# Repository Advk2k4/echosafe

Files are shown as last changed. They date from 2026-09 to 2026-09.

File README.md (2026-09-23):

# EchoSafe

Wearable, around-the-ear sound-alert device for people who are deaf or hard
of hearing. ESP32-S3, 4 directional MEMS mics, on-device ML sound
classification, 4 directional haptic motors.

See [`CLAUDE.md`](CLAUDE.md) for architecture, pin mapping, ML pipeline, and
current status. See [`CONSOLIDATION_NOTES.md`](CONSOLIDATION_NOTES.md) for
where this repo's contents came from.

```
firmware/   ESP32-S3 Arduino sketches (full system, single-mic reference, data collector)
ml/         Training pipeline + dataset
hardware/   5 KiCad projects: central pod + 4 earpiece modules (PCB layout not yet started)
docs/       Supplementary reference docs
```

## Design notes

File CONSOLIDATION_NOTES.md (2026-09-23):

# Consolidation Notes

This repo was assembled from several scattered folders under `~/Documents/`
on 2026-09-11. Nothing in the original folders was deleted or moved — only
copied. This file records what came from where, and what was deliberately
left out.

## Brought in

| Source | Went to | Notes |
|---|---|---|
| `EchoSafe_ML/echosafe_full_system/` | `firmware/echosafe_full_system/` | Most recently modified firmware, primary target |
| `EchoSafe_ML/echosafe_inference/` | `firmware/echosafe_inference/` | Kept as minimal bring-up reference; `echosafe_full_system.ino` depends on this folder via relative include — keep them siblings |
| `EchoSafe_ML/echosafe_feature_collector/` | `firmware/echosafe_feature_collector/` | Data collection firmware |
| `EchoSafe_ML/mic_oldML.c` | `firmware/mic_oldML.c` | Historical reference, copied verbatim |
| `EchoSafe_ML/uploadLittleFS.ino` | `firmware/uploadLittleFS/uploadLittleFS.ino` | Debug utility (moved into its own sketch folder 2026-09-22 so arduino-cli can compile it in place) |
| `EchoSafe_ML/data/*.wav` | `firmware/data/` | Alert sound files |
| `EchoSafe_ML/retrain.py`, `train_on_esp32_features.py`, `download_sounds.py`, `play_sound.py`, `serial_logger.py`, `quick_start.py` | `ml/` | ML pipeline scripts |
| `EchoSafe_ML/echosafe_dataset.npz` | `ml/echosafe_dataset.npz` | 1059-sample dataset, current |
| `EchoSafe_ML/IMPLEMENTATION_SUMMARY.md` | `docs/IMPLEMENTATION_SUMMARY.md` | Data collection strategy reference |
| `EchoSafe_RevA/` (entire folder) | `hardware/EchoSafe_RevA/` | Copied wholesale to preserve KiCad's relative-path project structure |

## Deliberately left out (and why)

- **`EchoSafe_ML/echosafe_fixed/echosafe_fixed.ino`** and
  **`EchoSafe_ML/final_test/final_test.ino`** — earlier drafts in the same
  lineage as `echosafe_full_system.ino`, superseded by it (confirmed by
  file mtimes and near-total diff overlap). Left in the original
  `EchoSafe_ML/` folder if ever needed for reference.
- **`EchoSafe_ML/trained_models/`** — two training snapshots from
  2026-02-12 using a `barks` class (not `gunshots`) on a ~361–373-sample
  dataset, predating the current 1059-sample/`gunshots` dataset. Stale.
- **`EchoSafe_ML/sounds/`** (~1.6GB, ESC-50 + playback sounds) — not
  copied due to size; regenerate locally via `python ml/download_sounds.py
  --dataset esc50 --output sounds/` if you need it for further data
  collection.
- **`EchoSafe_Audio/`** — an older/parallel ML effort: 16 hand-picked
  features (13 MFCCs + spectral centroid + bandwidth + zero-crossing-rate)
  instead of the current 403-feature pure-MFCC approach, different class
  set (`barks`, `VehicleApproaching` — not in the current 5-class set),
  lower accuracy (88.89% vs. 97.5%). Superseded, not merged in.
- **`EchoSafeTesting/`** — empty except for `.DS_Store`. Not carried
  forward.

## Known issues surfaced during consolidation (not yet fixed)

- **TL-mic workaround applied (2026-09-11):** `echosafe_full_system.ino`'s
  own comments documented a dead top-left (TL) mic (0.0000 RMS on last
  contact). `ML_MIC_CHANNEL` has been switched from `ONLY_LEFT` to
  `I2S_CHANNEL_FMT_ONLY_RIGHT` to match the documented workaround. This is
  a software mitigation, not a hardware fix — verify TL's actual state
  during bring-up. Also newly confirmed: `model_weights.h` was trained on
  the single-mic reference rig's audio (GPIO 5/6/7), not on either array
  channel, so real accuracy recovery requires retraining on array audio,
  not just this channel flip.
- **No PCB has ever been laid out or fabricated** for RevA — the KiCad
  `.kicad_pcb` file is empty. Any physical bring-up needs a breadboard/
  dev-kit setup, not an assembled board.
- **(Fixed 2026-09-11)** RevA schematic had no signal-level wiring at all.
  Added all I2S (2× mic pairs + speaker), I2C (mux + 4 haptic drivers),
  motor-output, and relevant power/enable nets via global labels (matching
  the sheet's existing power-rail label convention). Initial mic/motor
  quadrant assignment was a guess (numeric order); confirmed with the user
  same day as clockwise (MIC1/M1=TL, MIC2/M2=TR, MIC3/M3=BR, MIC4/M4=BL)
  and the wiring corrected to match — see CLAUDE.md's hardware section for
  full details of what changed and why.
- **(Fixed 2026-09-11)** Added C6-C9 (0.1µF decoupling caps) for each
  DRV2605's REG pin, per datasheet recommendation.
- **(Decided 2026-09-11, confirmed final)** Speaker architecture: 1×
  MAX98357A driving both 8Ω speakers in parallel (4Ω combined, within
  spec) — no second amp needed.
- **(Added, then replaced, 2026-09-11)** A placeholder USB-C connector was
  wired to the NPM1300 PMIC's native VBUS/CC1/CC2 pins, then removed the
  same day once the real power architecture was confirmed. No power switch
  or button added — confirmed out of scope for this design.
- **(Replaced 2026-09-11) Power architecture overhaul:** NPM1300 PMIC
  removed entirely (it was never actually wired even in the original
  pre-consolidation schematic — confirmed before deleting it) and replaced
  with the user's actual intended parts: J1 = TP4056_Module (HiLetGo,
  w/ protection), LD1 = LD1117V33 (SparkFun breakout), BT1 = 3.7V 350mAh
  LiPo. The three previously-separate rails (3V3_SYS/3V3_AUDIO/1V8_MIC)
  were consolidated into one 3V3_SYS rail from the single LD1117V33 —
  mics moved from a planned 1.8V supply to 3.3V (within ICS-43434 spec).
  Full capacitor mapping (C1-C17, all values and purposes) is in
  CLAUDE.md's "Power Architecture" section, including a correction: the
  DRV2605 REG-pin caps were originally set to 0.1µF (my initial guess);
  TI's datasheet actually specifies 1.0µF, corrected as part of this pass.
- **(Confirmed 2026-09-11) Board partition:** 4 earpiece modules (front-L/
  front-R each with 1 mic + 1 motor + 1 speaker + that mic's own
  decoupling cap; rear-L/rear-R each with just 1 mic + 1 motor + cap)
  plus 1 central pod holding everything else (ESP32, amp, mux, all 4
  haptic drivers, charging/regulation, battery, remaining caps).
- **(Added 2026-09-11) Harness connectors J2-J5**, one per earpiece
  module, documenting exact wire count (9 pins front/with speaker, 7
  pins rear/without) using **star topology** (confirmed with the user):
  a separate cable per module rather than one cable daisy-chaining
  through both mics on a shared I2S bus. The electrical nets are
  identical either way — the choice only affects cable routing and
  pod-side pin count. See CLAUDE.md for the full per-connector pin list.
- **(Done 2026-09-12) Split into 5 separate KiCad projects.** MIC1-4,
  M1-4, LS1-2, and their decoupling caps (C9-C12) moved out of
  `EchoSafe_RevA` (now specifically the central pod) into 4 new small
  projects: `EchoSafe_FrontLeft`, `EchoSafe_FrontRight`,
  `EchoSafe_RearLeft`, `EchoSafe_RearRight`. All 5 share one library
  folder (`EchoSafe_RevA/lib/symbols/`) via relative `sym-lib-table`
  paths — nothing duplicated. Each module connects to the pod's J2-J5
  connectors via a matching local `J1` using the same net names (a
  documentation convention, not an automatic cross-project link — the
  real connection is the physical cable). See CLAUDE.md's "Multi-Board
  Project Structure" section for the full breakdown.
- **(Clarified 2026-09-11)** `EchoSafe_v1_mech_layout.png` is outdated,
  disregard it. `EchoSafe.png` is the actual target look, minus the
  in-ear-bud cable shown in that render — speakers mount in the behind-
  ear housings instead.
- **(Done 2026-09-12) Footprints assigned across all 5 projects**,
  target confirmed as a compact near-final wearable (not an early
  bring-up prototype). Found and fixed two real bugs along the way:
  (1) the project split had silently wiped the mic/motor footprints that
  already existed pre-split — the instance generator zeroed every new
  component's footprint unconditionally, restored from the pre-split
  commit; (2) **footprint library registration (`fp-lib-table`) never
  existed in any version of this project** — same class of gap as the
  `sym-lib-table` issue found earlier — created it for all 5 projects and
  fixed the bare (unprefixed) footprint names that could never have
  resolved without it. Full per-part footprint table and reasoning is in
  CLAUDE.md's "Footprints" section. Footprints across all 5 projects are now fully assigned as of
  2026-09-13: LS1/LS2 = DigiKey 1528-4227-ND = Adafruit #4227 Mini Oval
  Speaker, 8Ω/1W/30x20x5mm, verified via DigiKey/Adafruit listings, not
  from memory. Connects via a Molex PicoBlade 1.25mm 2-pin connector
  (not bare wire) — footprint set to the matching PicoBlade receptacle,
  confirmed against KiCad's own footprint library source.
- **(Verified 2026-09-13)** The JST-SH harness connector footprint
  names from last session were flagged as unverified — checked them
  against KiCad's own footprints repo and found the guess was wrong
  (`BM0xB-SRSS-TB` prefix instead of the real `SM0xB-SRSS-TB`). Fixed
  all 8 occurrences across all 5 projects. Also checked TP4056 module
  pin spacing against multiple independent sources; 2.54mm/0.1"
  through-hole is standard, matching what was already assigned —
  worth a physical check against the actual board once it's in hand.
- **(Critical fix, 2026-09-13) Session-wide Y-axis coordinate bug.**
  Discovered KiCad is actually installed on this machine and ran real
  `kicad-cli sch erc` against every schematic for the first time —
  found that every label/wire/no-connect placed this session with a
  nonzero local Y pin offset used the wrong sign (`placement_y +
  local_y` instead of the correct `placement_y − local_y`, per
  KiCad's Y-up-symbol/Y-down-sheet convention). Fixed via a from-
  scratch single-pass correction across all 5 projects, verified by
  ERC before/after (all 4 modules: 21/21/17/17 → 9/9/8/8 violations,
  all now expected; central pod: down to 0 dangling labels / 0
  genuinely unconnected pins). Also fixed along the way: the ESP32's
  own 3V3/GND/EN pins had never been wired to anything (every
  peripheral got connected, the MCU's own supply pins were missed) —
  added the EN RC delay circuit per Espressif's actual hardware
  design guidelines (fetched, R=10k/C=1uF), and tied #PWR01 (an
  orphaned GND flag left over from the removed NPM1300) to GND. Full
  writeup in CLAUDE.md's "Critical fix" section, including the
  transform formula for anyone hand-editing .kicad_sch again.
- **(Replaced 2026-09-13) Mic footprint (`LGA_CAV_IVS`) didn't match
  the real part.** Found while starting PCB placement: the original
  SnapEDA-imported footprint (pre-dates this session) had GND as a
  tiny 0.127mm corner pad and an off-by-one pad numbering issue
  (a mechanical hole occupying pad "6", pushing the real 6th
  electrical pad to "7"). Checked against InvenSense's actual
  datasheet (DS-000069, fetched this session): GND is really a large
  ring pad around the acoustic port. Authored a replacement footprint
  (`ICS-43434_LGA6`) via KiCad's own `pcbnew` Python API directly from
  the datasheet's dimensions, round-trip verified by reloading it.
  Updated all 4 module projects' `fp-lib-table` and MIC1-4's
  `Footprint` property. One thing not expressible in a footprint file:
  the datasheet also calls for a drilled acoustic port hole through
  the PCB itself at this location — flagged in CLAUDE.md as a manual
  layout step, not something a footprint can encode.
- **(Fixed 2026-09-11)** RevA was missing 3 of 4 DRV2605 haptic drivers and
  the TCA9548A I2C mux the firmware architecture requires. Added U5
  (TCA9548A, verified pinout from TI datasheet SCPS207F) and U6/U7/U8
  (DRV2605LDGS, duplicated from the existing working U3). Placed only —
  not wired to the ESP32 or to each other yet.
- **(Fixed 2026-09-11)** `hardware/EchoSafe_RevA/EchoSafe_RevA/sym-lib-table`
  pointed at files that never existed, even in the original folder pre-
  dating this consolidation, plus 2 of 5 library nicknames didn't match
  the `lib_id` prefixes actually used in the schematic. Corrected to real
  files via `${KIPRJMOD}`-relative paths. Previously any attempt to place
  a *new* instance of these parts in KiCad would have failed; existing
  placements worked only because `.kicad_sch` caches symbols inline.
- The original `EchoSafe_ML/CLAUDE.md` documented `echosafe_inference.ino`
  as having WAV playback / LittleFS / a fuller command set — the actual
  current file has none of that (mic + inference only). Fixed in this
  repo's `CLAUDE.md`.
- `EchoSafe_ML/` had no `.gitignore` despite its own docs claiming one
  excluded `*.npz` etc. This repo has a real one.

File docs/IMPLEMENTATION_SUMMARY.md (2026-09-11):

# EchoSafe Implementation Summary

## What We've Built

A complete end-to-end system for collecting real-world audio features directly from your ESP32 and training a classifier that **perfectly matches** the deployment environment.

## Key Innovation

**Problem**: Training on librosa features ≠ ESP32 features → poor accuracy
**Solution**: Collect features FROM the ESP32 → Train on exact same distribution → Perfect match!

---

## Files Created

### 1. **echosafe_feature_collector.ino** (ESP32 Firmware)
- Captures audio from I2S MEMS microphone
- Extracts MFCC features on-device
- Outputs features via serial in structured format
- **Commands**: 
  - `c` - Capture one sample
  - `r` - Start continuous recording (every 2s)
  - `s` - Stop continuous recording

### 2. **serial_logger.py** (Data Collection)
- Connects to ESP32 via serial
- Captures feature vectors in real-time
- Prompts for labels
- Builds labeled dataset (.npz format)
- **Interactive commands**:
  - `c` - Capture one sample
  - `a` - Auto-capture mode
  - `s` - Save and show stats
  - `q` - Save and quit

### 3. **download_sounds.py** (Dataset Downloader)
- Downloads ESC-50 environmental sound dataset
- Organizes sounds by category
- Creates folders for custom recordings
- Lists recommended categories for safety/wearable devices

### 4. **play_sound.py** (Sound Playback)
- Plays sounds through speakers for mic capture
- Interactive category browser
- Batch playback with configurable pauses
- Can record ambient silence samples

### 5. **train_on_esp32_features.py** (Model Training)
- Trains on ACTUAL ESP32 features
- Automatic train/val/test split
- Feature standardization
- Exports trained model
- **Optional**: Exports model as C code for ESP32

### 6. **README.md** (Complete Guide)
- Full workflow documentation
- Hardware setup instructions
- Troubleshooting guide
- Best practices

### 7. **quick_start.py** (Setup Assistant)
- Checks dependencies
- Guides through first collection
- Interactive setup wizard

---

## Recommended Sound Datasets

### 1. **ESC-50** (Best for General Environmental Sounds)
- **Source**: https://github.com/karolpiczak/ESC-50
- **Size**: ~600MB, 2,000 sounds
- **Categories**: 50 classes including:
  - Animals: dog, cat, rooster, bird
  - Natural: rain, wind, water, thunder
  - Human: crying baby, coughing, sneezing, footsteps
  - Interior/Domestic: door knock, keyboard, clock alarm, vacuum
  - Urban: siren, car horn, engine, helicopter
- **Download**: `python download_sounds.py --dataset esc50`

### 2. **UrbanSound8K** (Urban/City Sounds)
- **Source**: https://urbansounddataset.weebly.com/urbansound8k.html
- **Size**: ~6GB, 8,732 sounds
- **Categories**: Air conditioner, car horn, children playing, dog bark, drilling, engine idling, gun shot, jackhammer, siren, street music
- **Use case**: Safety/alert sounds for wearable
- **Download**: Manual download from website (requires citation agreement)

### 3. **FSD50K** (Freesound Dataset)
- **Source**: https://zenodo.org/record/4060432
- **Size**: ~50GB, 51,197 sounds
- **Categories**: 200 classes from AudioSet ontology
- **Use case**: Most comprehensive for any domain
- **Download**: From Zenodo (large!)

### 4. **AudioSet** (Google's Audio Dataset)
- **Source**: https://research.google.com/audioset/
- **Size**: ~2 million YouTube clips
- **Categories**: 632 classes (very comprehensive)
- **Use case**: When you need very specific sounds
- **Download**: Requires YouTube downloading (complex)

### 5. **Freesound.org** (Individual Sounds)
- **Source**: https://freesound.org/
- **Best for**: Custom, specific sounds
- **Search**: By keyword, browse by category
- **License**: Various (check individual sounds)
- **Use case**: When datasets don't have what you need

---

## Recommended Sound Categories for EchoSafe

Based on safety/wearable use case:

### High Priority (Collect First)
```
✅ Emergency Sounds
   - siren (police, ambulance, fire)
   - car_horn
   - alarm_clock / alarm_bell
   - glass_breaking
   
✅ Human Alerts
   - crying_baby
   - screaming (if available)
   - coughing
   - sneezing
   
✅ Environmental Alerts
   - dog_bark (aggressive vs friendly)
   - door_knock
   - doorbell
   
✅ Background/Calibration
   - silence (ambient room noise)
   - white_noise
   - rain
   - keyboard_typing
```

### Medium Priority
```
🔸 Activity Sounds
   - footsteps
   - clapping
   - vacuum_cleaner
   - washing_machine
   
🔸 Mechanical
   - engine
   - drilling
   - chainsaw
   - hand_saw
```

### Custom/Domain-Specific
```
🔹 Record Your Own
   - Specific alarm sounds in your environment
   - Voice commands ("help", "emergency")
   - Equipment-specific sounds
   - Environmental sounds unique to deployment location
```

---

## Data Collection Strategy

### Phase 1: Download ESC-50
```bash
python download_sounds.py --dataset esc50 --output sounds/
```

### Phase 2: Organize Priority Sounds
```bash
python play_sound.py --interactive sounds/playback_sounds
```

Pick categories from ESC-50:
- dog_bark
- siren
- car_horn
- crying_baby
- alarm_clock
- glass_breaking
- door_knock

### Phase 3: Record Custom Sounds

**Silence (Most Important!)**:
```bash
# Record ambient noise in your deployment environment
python play_sound.py --record-silence --silence-duration 2 --silence-output silence_001.wav

# Record 20-30 different silence samples:
# - Different rooms
# - Different times of day
# - With/without HVAC
# - With/without background conversation
```

**Custom Alarms/Alerts**:
```bash
# Create category for your specific alarm
python download_sounds.py --dataset custom --custom-name "my_alarm"

# Record your actual alarm sound:
# - Play through speaker
# - Record directly to .wav file (16kHz mono recommended)
# - Place in sounds/custom_recordings/my_alarm/
```

### Phase 4: Systematic Collection

**Recommended workflow**:

1. **Start with 6 core classes** (20-30 samples each):
   - silence
   - dog_bark
   - siren
   - car_horn
   - alarm_clock
   - crying_baby

2. **Vary conditions**:
   - Near (0.5m), medium (2m), far (5m) distances
   - Low, medium, high volumes
   - With/without background noise
   - Different angles

3. **Collection tips**:
   - Position speaker at consistent distance from mic
   - Label consistently (use same names!)
   - Take breaks every 10-15 samples
   - Verify features look good in serial output

---

## Expected Performance

With good data collection:

| Metric | Expected Value |
|---|---|
| Training Accuracy | 95-99% |
| Validation Accuracy | 90-95% |
| Test Accuracy | 85-93% |
| Inference Time (ESP32) | 50-150ms |

**If accuracy is lower**:
- Collect more samples (aim for 30-50 per class)
- Ensure high audio quality
- Check label consistency
- Increase model size: `--hidden 256 128 64`

---

## Complete Workflow Timeline

### Day 1: Setup (1-2 hours)
- Upload firmware
- Verify I2S microphone works
- Download ESC-50 dataset
- Test capture with `c` command

### Day 2-3: Data Collection (4-6 hours)
- **Session 1**: Silence class (30 samples, 1 hour)
  - Record ambient noise in different conditions
- **Session 2**: ESC-50 sounds (3-4 classes, 2 hours)
  - Play sounds, capture, label
- **Session 3**: More ESC-50 sounds (3-4 classes, 2 hours)
- **Session 4**: Custom sounds (1-2 classes, 1 hour)

### Day 4: Training (1 hour)
- Train model on collected features
- Evaluate performance
- Identify weak classes → collect more data if needed

### Day 5: Refinement (2-3 hours)
- Collect additional samples for low-accuracy classes
- Retrain
- Export model to C code
- Create inference firmware

### Week 2: Deployment & Testing
- Deploy to ESP32
- Real-world testing
- Fix edge cases
- Final tuning

---

## Key Success Factors

### ✅ DO:
1. **Always collect a "silence" class** with ambient noise
2. **Use consistent label names** (snake_case recommended)
3. **Vary recording conditions** (distance, volume, background)
4. **Collect 20-30 samples minimum** per class
5. **Test on real deployment environment** before finalizing

### ❌ DON'T:
1. Skip the silence class
2. Use only one recording distance
3. Ignore class imbalance (collect equal samples)
4. Change labels mid-collection (dog_bark vs dog-bark vs dogbark)
5. Deploy without thorough testing

---

## Where to Get Help

1. **Arduino ESP32 Issues**:
   - https://github.com/espressif/arduino-esp32
   - Check Serial Monitor for error messages

2. **I2S Microphone Issues**:
   - https://docs.espressif.com/projects/esp-idf/en/latest/esp32s3/api-reference/peripherals/i2s.html
   - Verify wiring with pin definitions in code

3. **Dataset Questions**:
   - ESC-50: https://github.com/karolpiczak/ESC-50
   - UrbanSound8K: https://urbansounddataset.weebly.com/
   - Freesound: https://freesound.org/help/

4. **Machine Learning**:
   - TensorFlow docs: https://www.tensorflow.org/
   - Feature engineering: Librosa docs (for reference)

---

## Next Steps After Basic Implementation

1. **Model Optimization**:
   - Quantization (float32 → int8)
   - Pruning
   - Knowledge distillation

2. **Advanced Features**:
   - Add spectral features (spectral centroid, rolloff)
   - Delta and delta-delta MFCCs
   - Temporal modeling (LSTM/GRU)

3. **Production Features**:
   - Confidence thresholds
   - Multi-class detection (detect multiple sounds)
   - Noise robustness testing
   - Power optimization

4. **Continuous Improvement**:
   - Log misclassifications
   - Collect edge cases
   - Periodic retraining
   - A/B testing

---

## Conclusion

This system gives you:
- ✅ **Perfect feature matching** (train = deployment)
- ✅ **Real-world performance** (actual device data)
- ✅ **Easy data collection** (plug-and-play workflow)
- ✅ **Iterative improvement** (collect more → retrain)

The key insight: **Don't try to match librosa to ESP32. Collect from ESP32 and train on that!**

Good luck with EchoSafe! 🎤🔊🤖

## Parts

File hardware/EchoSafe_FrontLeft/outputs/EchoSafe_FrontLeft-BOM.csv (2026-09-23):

Refs | Value | Footprint | Qty | DNP
C9 | 1uF | Capacitor_SMD:C_0603_1608Metric | 1
J1 | Conn_Harness_09 | Connectors_PinMarked:JST_SH_SM09B-SRSS-TB_1x09-1MP_P1.00mm_Horizontal | 1
LS1 | Adafruit_4227_8ohm_1W | Connectors_PinMarked:Molex_PicoBlade_53261-0271_1x02-1MP_P1.25mm_Horizontal | 1
M1 | C0720B001F | C0720B001F:XDCR_C0720B001F | 1
MIC1 | ICS-43434 | ICS-43434:ICS-43434_LGA6 | 1

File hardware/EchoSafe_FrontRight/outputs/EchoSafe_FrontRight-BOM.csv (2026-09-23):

Refs | Value | Footprint | Qty | DNP
C10 | 1uF | Capacitor_SMD:C_0603_1608Metric | 1
J1 | Conn_Harness_09 | Connectors_PinMarked:JST_SH_SM09B-SRSS-TB_1x09-1MP_P1.00mm_Horizontal | 1
LS2 | Adafruit_4227_8ohm_1W | Connectors_PinMarked:Molex_PicoBlade_53261-0271_1x02-1MP_P1.25mm_Horizontal | 1
M2 | C0720B001F | C0720B001F:XDCR_C0720B001F | 1
MIC2 | ICS-43434 | ICS-43434:ICS-43434_LGA6 | 1

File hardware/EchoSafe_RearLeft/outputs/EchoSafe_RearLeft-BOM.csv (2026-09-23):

Refs | Value | Footprint | Qty | DNP
C12 | 1uF | Capacitor_SMD:C_0603_1608Metric | 1
J1 | Conn_Harness_07 | Connectors_PinMarked:JST_SH_SM07B-SRSS-TB_1x07-1MP_P1.00mm_Horizontal | 1
M4 | C0720B001F | C0720B001F:XDCR_C0720B001F | 1
MIC4 | ICS-43434 | ICS-43434:ICS-43434_LGA6 | 1

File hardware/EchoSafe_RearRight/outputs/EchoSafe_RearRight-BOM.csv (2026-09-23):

Refs | Value | Footprint | Qty | DNP
C11 | 1uF | Capacitor_SMD:C_0603_1608Metric | 1
J1 | Conn_Harness_07 | Connectors_PinMarked:JST_SH_SM07B-SRSS-TB_1x07-1MP_P1.00mm_Horizontal | 1
M3 | C0720B001F | C0720B001F:XDCR_C0720B001F | 1
MIC3 | ICS-43434 | ICS-43434:ICS-43434_LGA6 | 1

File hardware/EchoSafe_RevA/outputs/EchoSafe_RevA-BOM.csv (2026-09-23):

Refs | Value | Footprint | Qty | DNP
BT1 | Battery_Cell | Connector_JST:JST_PH_S2B-PH-K_1x02_P2.00mm_Horizontal | 1
C1,C2,C16 | 10uF | Capacitor_SMD:C_0603_1608Metric | 3
C3,C4,C15 | 100nF | Capacitor_SMD:C_0603_1608Metric | 3
C5,C6,C7,C8,C13,C14,C17,C18 | 1uF | Capacitor_SMD:C_0603_1608Metric | 8
J1 | TP4056_Module | TP4056_Module:TP4056_Module | 1
J2,J3 | Conn_Harness_09 | Connectors_PinMarked:JST_SH_SM09B-SRSS-TB_1x09-1MP_P1.00mm_Horizontal | 2
J4,J5 | Conn_Harness_07 | Connectors_PinMarked:JST_SH_SM07B-SRSS-TB_1x07-1MP_P1.00mm_Horizontal | 2
LD1 | LD1117V33 | Connector_PinHeader_2.54mm:PinHeader_1x03_P2.54mm_Vertical | 1
R1,R2 | 10k | Resistor_SMD:R_0603_1608Metric | 2
U1 | ESP32-S3-WROOM-1-N16R8 | ESP32-S3-WROOM-1:ESP32-S3-WROOM-1_EXP | 1
U2 | MAX98357AETE+T | MAX98357AETE-T:21-0136I_T1633-4_MXM | 1
U3,U6,U7,U8 | DRV2605LDGS | Package_SO:VSSOP-10_3x3mm_P0.5mm | 4
U5 | TCA9548A | Package_SO:TSSOP-24_4.4x7.8mm_P0.65mm | 1

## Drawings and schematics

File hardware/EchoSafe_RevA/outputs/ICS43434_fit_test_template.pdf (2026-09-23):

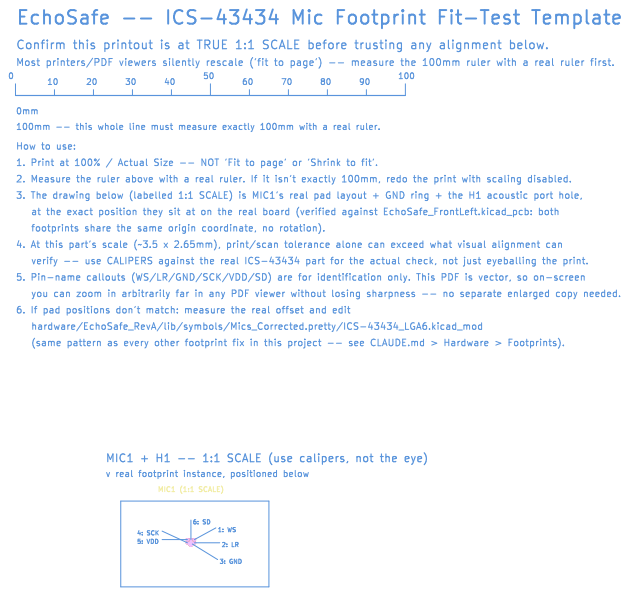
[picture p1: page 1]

80 hardware/EchoSafe_RevA/lib/symbols/Mics_Corrected.pretty/ICS-43434_LGA6.kicad_mod

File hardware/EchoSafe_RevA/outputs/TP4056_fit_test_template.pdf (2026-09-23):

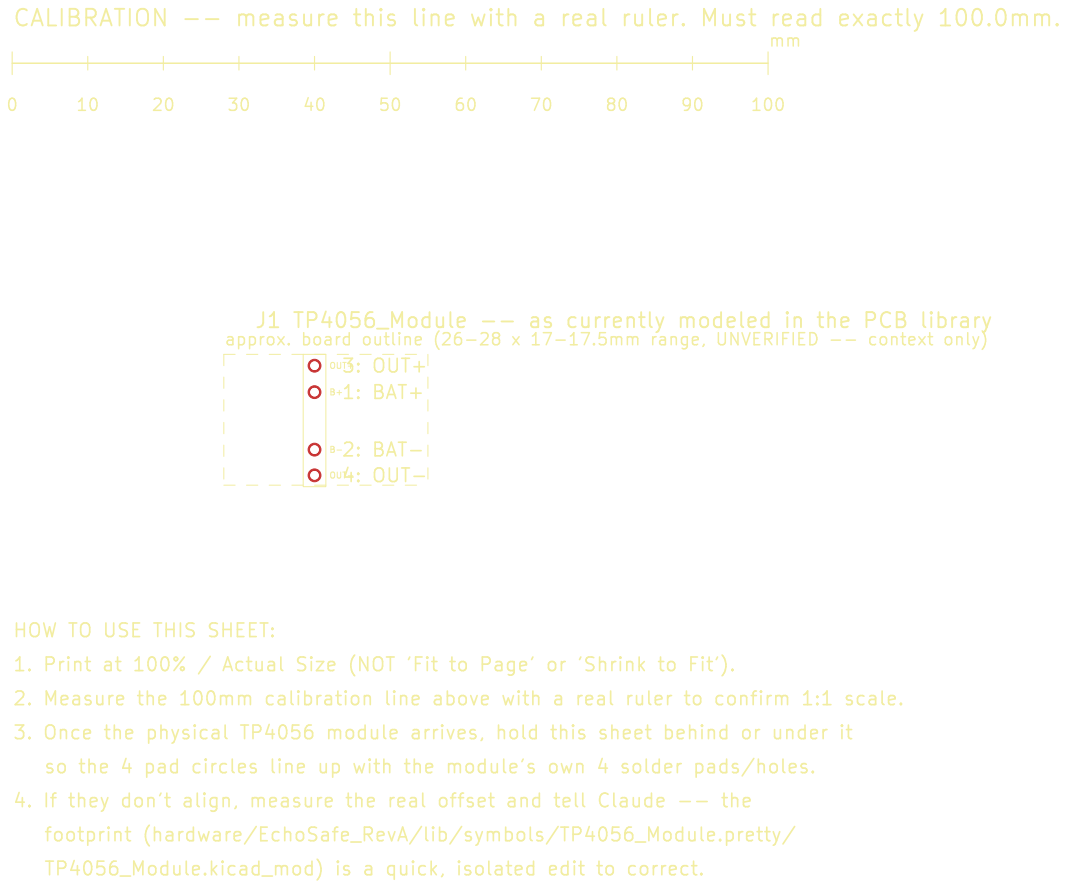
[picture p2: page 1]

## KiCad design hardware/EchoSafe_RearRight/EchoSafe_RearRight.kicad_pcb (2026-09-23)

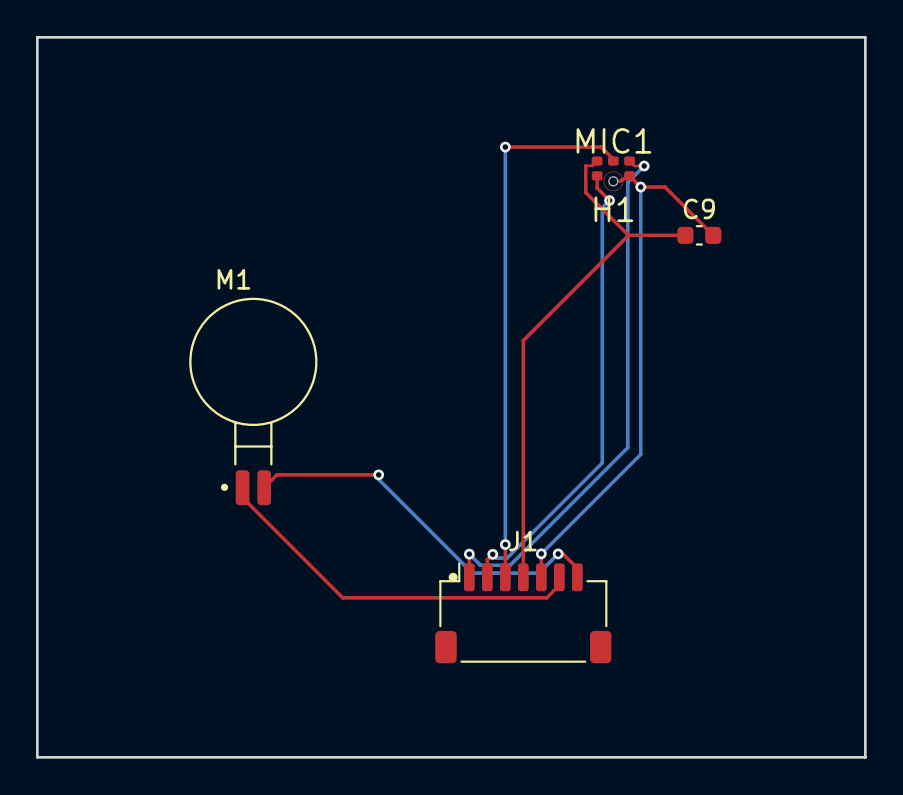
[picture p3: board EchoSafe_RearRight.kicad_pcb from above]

Board: 2 copper layers, 46.0 x 40.0 mm, 5 parts (0 on the bottom side), 7 nets.

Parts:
C9: 1uF; C_0603_1608Metric
H1: Acoustic_Port_0.5mm
J1: JST_SH_SM07B-SRSS-TB_1x07-1MP_P1.00mm_Horizontal
M1: XDCR_C0720B001F
MIC1: ICS-43434_LGA6

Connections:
3V3_SYS: C9.1, J1.4, MIC1.5
GND: C9.2, J1.5, MIC1.2, MIC1.3
MIC_BOT_SCK: J1.2, MIC1.4
MIC_BOT_SD: J1.3, MIC1.6
MIC_BOT_WS: J1.1, MIC1.1
MOTOR_BR_OUTN: J1.7, M1.2
MOTOR_BR_OUTP: J1.6, M1.1

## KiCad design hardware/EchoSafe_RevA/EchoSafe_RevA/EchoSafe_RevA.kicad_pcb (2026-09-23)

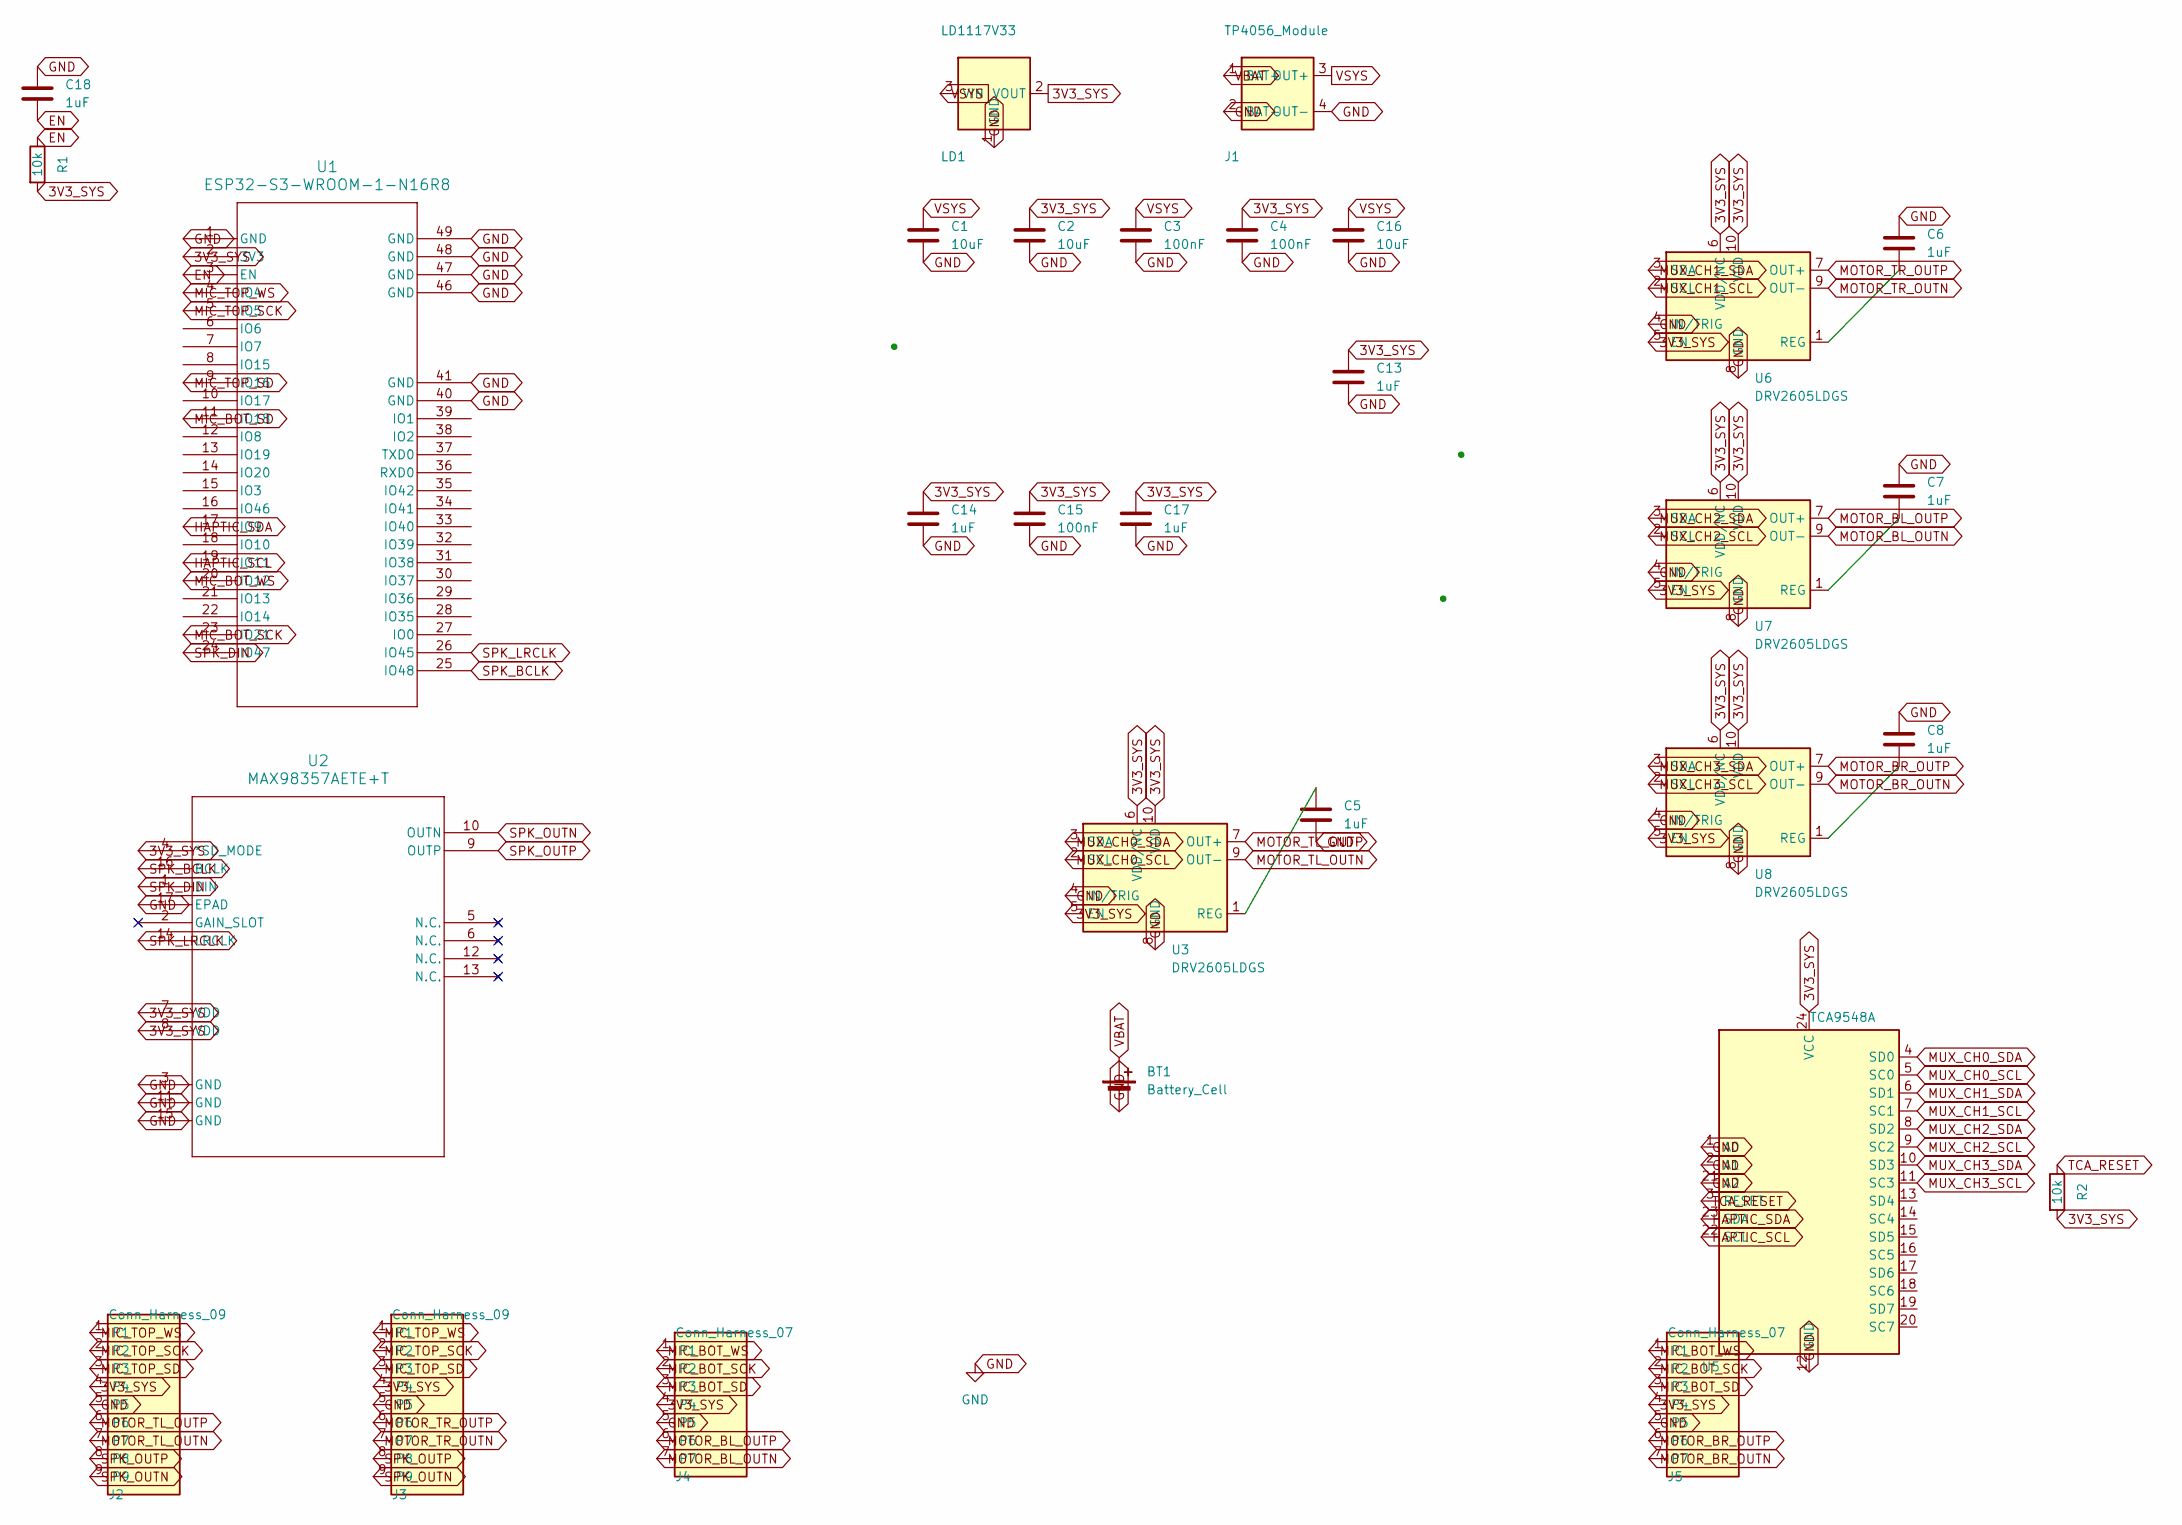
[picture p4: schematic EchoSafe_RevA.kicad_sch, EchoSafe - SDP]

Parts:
BT1: Battery_Cell; JST_PH_S2B-PH-K_1x02_P2.00mm_Horizontal
C1, C2, C16: 10uF; C_0603_1608Metric
C3, C4, C15: 100nF; C_0603_1608Metric
C5, C6, C7, C8, C13, C14, C17, C18: 1uF; C_0603_1608Metric
J1: TP4056_Module
J2, J3: Conn_Harness_09; JST_SH_SM09B-SRSS-TB_1x09-1MP_P1.00mm_Horizontal
J4, J5: Conn_Harness_07; JST_SH_SM07B-SRSS-TB_1x07-1MP_P1.00mm_Horizontal
LD1: LD1117V33; PinHeader_1x03_P2.54mm_Vertical
R1, R2: 10k; R_0603_1608Metric
U1: ESP32-S3-WROOM-1-N16R8; ESP32-S3-WROOM-1_EXP
U2: MAX98357AETE+T; 21-0136I_T1633-4_MXM
U3, U6, U7, U8: DRV2605LDGS; VSSOP-10_3x3mm_P0.5mm
U5: TCA9548A; TSSOP-24_4.4x7.8mm_P0.65mm

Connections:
3V3_SYS: C2.1, C4.1, C13.1, C14.1, C15.1, C17.1, J2.4, J3.4, J4.4, J5.4, LD1.2 (VOUT), R1.2, R2.2, U1.2 (3V3), U2.4 (*SD_MODE), U2.7 (VDD), U2.8 (VDD), U3.5 (EN), U3.6 (VDD/NC), U3.10 (VDD), U5.24 (VCC), U6.5 (EN), U6.6 (VDD/NC), U6.10 (VDD), U7.5 (EN), U7.6 (VDD/NC), U7.10 (VDD), U8.5 (EN), U8.6 (VDD/NC), U8.10 (VDD)
EN: C18.2, R1.1, U1.3 (EN)
GND: BT1.2 (-), C1.2, C2.2, C3.2, C4.2, C5.2, C6.1, C7.1, C8.1, C13.2, C14.2, C15.2, C16.2, C17.2, C18.1, J1.2 (BAT-), J1.4 (OUT-), J2.5, J3.5, J4.5, J5.5, LD1.1 (GND), U1.1 (GND), U1.40 (GND), U1.41 (GND), U1.46 (GND), U1.47 (GND), U1.48 (GND), U1.49 (GND), U2.3 (GND), U2.11 (GND), U2.15 (GND), U2.17 (EPAD), U3.4 (IN/TRIG), U3.8 (GND), U5.1 (A0), U5.2 (A1), U5.12 (GND), U5.21 (A2), U6.4 (IN/TRIG), U6.8 (GND), U7.4 (IN/TRIG), U7.8 (GND), U8.4 (IN/TRIG), U8.8 (GND)
HAPTIC_SCL: U1.19 (IO11), U5.22 (SCL)
HAPTIC_SDA: U1.17 (IO9), U5.23 (SDA)
MIC_BOT_SCK: J4.2, J5.2, U1.23 (IO21)
MIC_BOT_SD: J4.3, J5.3, U1.11 (IO18)
MIC_BOT_WS: J4.1, J5.1, U1.20 (IO12)
MIC_TOP_SCK: J2.2, J3.2, U1.5 (IO5)
MIC_TOP_SD: J2.3, J3.3, U1.9 (IO16)
MIC_TOP_WS: J2.1, J3.1, U1.4 (IO4)
MOTOR_BL_OUTN: J4.7, U7.9 (OUT-)
MOTOR_BL_OUTP: J4.6, U7.7 (OUT+)
MOTOR_BR_OUTN: J5.7, U8.9 (OUT-)
MOTOR_BR_OUTP: J5.6, U8.7 (OUT+)
MOTOR_TL_OUTN: J2.7, U3.9 (OUT-)
MOTOR_TL_OUTP: J2.6, U3.7 (OUT+)
MOTOR_TR_OUTN: J3.7, U6.9 (OUT-)
MOTOR_TR_OUTP: J3.6, U6.7 (OUT+)
MUX_CH0_SCL: U3.2 (SCL), U5.5 (SC0)
MUX_CH0_SDA: U3.3 (SDA), U5.4 (SD0)
MUX_CH1_SCL: U5.7 (SC1), U6.2 (SCL)
MUX_CH1_SDA: U5.6 (SD1), U6.3 (SDA)
MUX_CH2_SCL: U5.9 (SC2), U7.2 (SCL)
MUX_CH2_SDA: U5.8 (SD2), U7.3 (SDA)
MUX_CH3_SCL: U5.11 (SC3), U8.2 (SCL)
MUX_CH3_SDA: U5.10 (SD3), U8.3 (SDA)
NET_U3_REG: C5.1, U3.1 (REG)
NET_U6_REG: C6.2, U6.1 (REG)
NET_U7_REG: C7.2, U7.1 (REG)
NET_U8_REG: C8.2, U8.1 (REG)
SPK_BCLK: U1.25 (IO48), U2.16 (BCLK)
SPK_DIN: U1.24 (IO47), U2.1 (DIN)
SPK_LRCLK: U1.26 (IO45), U2.14 (LRCLK)
SPK_OUTN: J2.9, J3.9, U2.10 (OUTN)
SPK_OUTP: J2.8, J3.8, U2.9 (OUTP)
TCA_RESET: R2.1, U5.3 (RESET)
VBAT: BT1.1 (+), J1.1 (BAT+)
VSYS: C1.1, C3.1, C16.1, J1.3 (OUT+), LD1.3 (VIN)

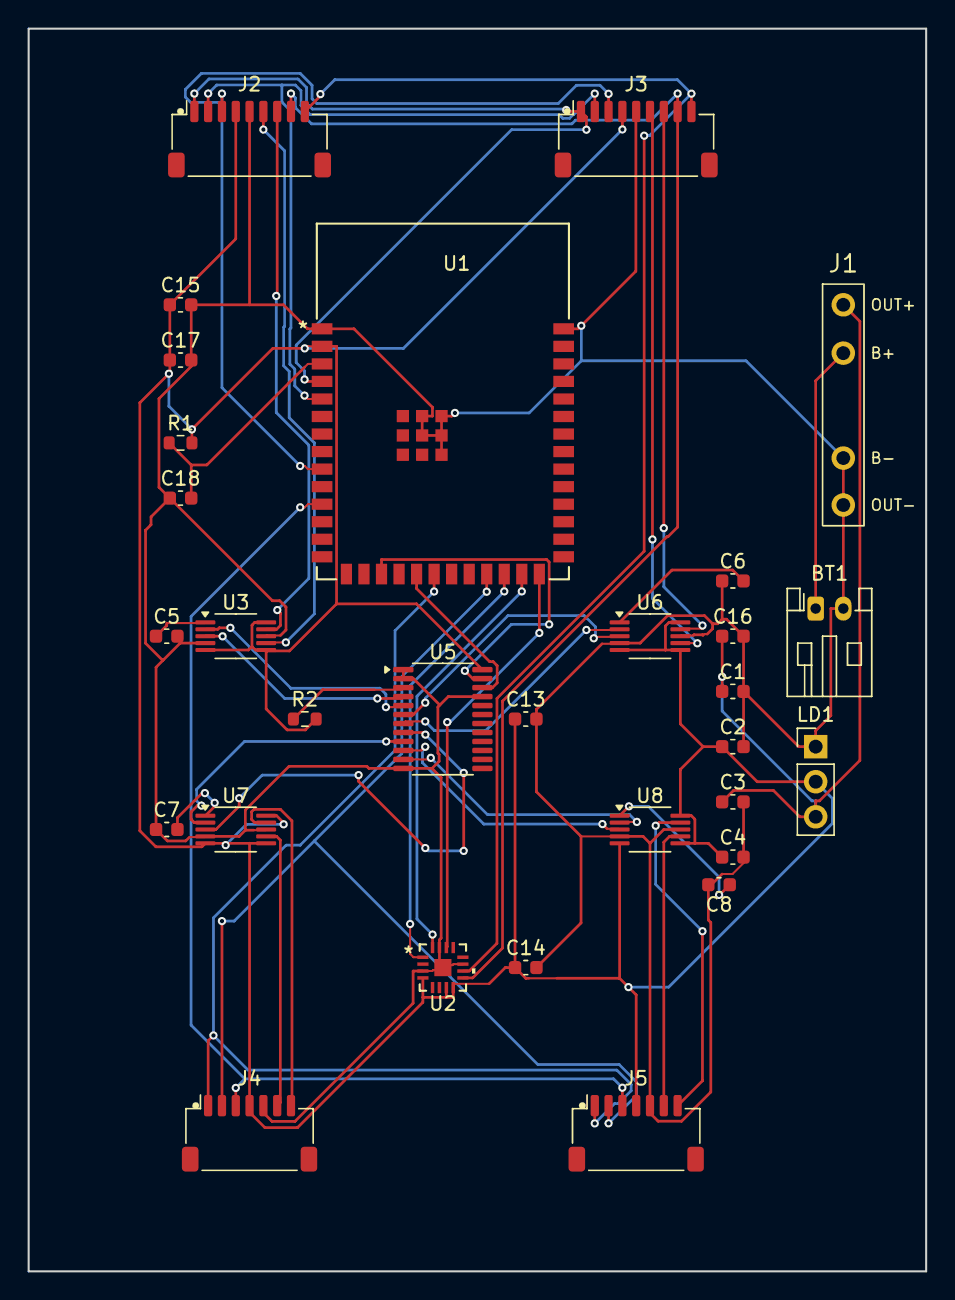
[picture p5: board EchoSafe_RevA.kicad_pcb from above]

Board: 2 copper layers, 65.0 x 90.0 mm, 30 parts (0 on the bottom side), 39 nets.

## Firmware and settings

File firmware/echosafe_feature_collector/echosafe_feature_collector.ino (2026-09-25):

/*
 * EchoSafe Feature Collection Firmware
 * ESP32-S3-N16R8 with I2S MEMS Microphone
 * 
 * Purpose: Capture audio, extract features, output to serial for labeling
 * 
 * Hardware:
 * - ESP32-S3-N16R8 (16MB Flash, 8MB PSRAM)
 * - I2S MEMS Microphone (ICS-43434 or INMP441)
 * 
 * Commands:
 * - 'c': Capture audio and extract features
 * - 'r': Start continuous recording mode (auto-capture every 2 seconds)
 * - 's': Stop continuous mode
 */

#include <driver/i2s_std.h>
#include <math.h>

// ============= CONFIGURATION =============
#define SAMPLE_RATE       16000    // 16kHz - good for voice/environmental sounds
#define SAMPLE_BITS       32       // I2S bits per sample
#define CHANNELS          1        // Mono
#define FRAME_SIZE        512      // Samples per frame for FFT
#define FRAME_STEP        256      // Hop size (50% overlap)
#define NUM_MFCC          13       // Number of MFCC coefficients
#define NUM_FRAMES        31       // ~1 second of audio (16000 / 512)
#define FFT_SIZE          512      // FFT size (must be power of 2)
#define MEL_BINS          26       // Number of mel filter banks

// I2S Pin Configuration (adjust for your board)
#define I2S_WS            5        // Word Select (LRCLK)
#define I2S_SD            6        // Serial Data (DOUT)
#define I2S_SCK           7        // Serial Clock (BCLK)
#define I2S_PORT          I2S_NUM_0

// Feature extraction parameters
#define PRE_EMPHASIS      0.97f
#define MEL_MIN_FREQ      0.0f
#define MEL_MAX_FREQ      8000.0f  // Nyquist frequency

// ============= GLOBAL BUFFERS =============
float audio_buffer[FRAME_SIZE];
float mfcc_features[NUM_FRAMES][NUM_MFCC];
int32_t i2s_buffer[FRAME_SIZE];  // I2S read buffer (32-bit samples)

// FFT and Mel filter bank buffers
float fft_real[FFT_SIZE];
float fft_imag[FFT_SIZE];
float power_spectrum[FFT_SIZE / 2 + 1];
float mel_energies[MEL_BINS];

// Pre-computed mel filter bank
float mel_filters[MEL_BINS][FFT_SIZE / 2 + 1];

// DCT matrix for MFCC
float dct_matrix[NUM_MFCC][MEL_BINS];

// State
bool continuous_mode = false;
static i2s_chan_handle_t mic_rx_handle = NULL;

// ============= HELPER FUNCTIONS =============

// Convert frequency to mel scale
float hz_to_mel(float hz) {
  return 2595.0f * log10f(1.0f + hz / 700.0f);
}

// Convert mel to frequency
float mel_to_hz(float mel) {
  return 700.0f * (powf(10.0f, mel / 2595.0f) - 1.0f);
}

// Initialize mel filter banks
void init_mel_filters() {
  float mel_min = hz_to_mel(MEL_MIN_FREQ);
  float mel_max = hz_to_mel(MEL_MAX_FREQ);
  float mel_step = (mel_max - mel_min) / (MEL_BINS + 1);
  
  float mel_points[MEL_BINS + 2];
  for (int i = 0; i < MEL_BINS + 2; i++) {
    mel_points[i] = mel_to_hz(mel_min + i * mel_step);
  }
  
  for (int i = 0; i < MEL_BINS; i++) {
    for (int j = 0; j <= FFT_SIZE / 2; j++) {
      float freq = (float)j * SAMPLE_RATE / FFT_SIZE;
      
      if (freq >= mel_points[i] && freq <= mel_points[i + 1]) {
        mel_filters[i][j] = (freq - mel_points[i]) / (mel_points[i + 1] - mel_points[i]);
      } else if (freq >= mel_points[i + 1] && freq <= mel_points[i + 2]) {
        mel_filters[i][j] = (mel_points[i + 2] - freq) / (mel_points[i + 2] - mel_points[i + 1]);
      } else {
        mel_filters[i][j] = 0.0f;
      }
    }
  }
}

// Initialize DCT matrix
void init_dct_matrix() {
  for (int i = 0; i < NUM_MFCC; i++) {
    for (int j = 0; j < MEL_BINS; j++) {
      dct_matrix[i][j] = cosf(M_PI * i * (j + 0.5f) / MEL_BINS);
      if (i == 0) {
        dct_matrix[i][j] *= sqrtf(1.0f / MEL_BINS);
      } else {
        dct_matrix[i][j] *= sqrtf(2.0f / MEL_BINS);
      }
    }
  }
}

// Simple FFT (Cooley-Tukey radix-2)
void fft(float* real, float* imag, int n) {
  // Bit-reversal permutation
  int j = 0;
  for (int i = 0; i < n - 1; i++) {
    if (i < j) {
      float temp = real[i];
      real[i] = real[j];
      real[j] = temp;
      temp = imag[i];
      imag[i] = imag[j];
      imag[j] = temp;
    }
    int k = n / 2;
    while (k <= j) {
      j -= k;
      k /= 2;
    }
    j += k;
  }
  
  // FFT computation
  for (int len = 2; len <= n; len *= 2) {
    float angle = -2.0f * M_PI / len;
    float wlen_real = cosf(angle);
    float wlen_imag = sinf(angle);
    
    for (int i = 0; i < n; i += len) {
      float w_real = 1.0f;
      float w_imag = 0.0f;
      
      for (int j = 0; j < len / 2; j++) {
        int idx1 = i + j;
        int idx2 = i + j + len / 2;
        
        float t_real = w_real * real[idx2] - w_imag * imag[idx2];
        float t_imag = w_real * imag[idx2] + w_imag * real[idx2];
        
        real[idx2] = real[idx1] - t_real;
        imag[idx2] = imag[idx1] - t_imag;
        real[idx1] += t_real;
        imag[idx1] += t_imag;
        
        float temp_w = w_real;
        w_real = w_real * wlen_real - w_imag * wlen_imag;
        w_imag = temp_w * wlen_imag + w_imag * wlen_real;
      }
    }
  }
}

// Hamming window
void apply_hamming_window(float* buffer, int size) {
  for (int i = 0; i < size; i++) {
    float window = 0.54f - 0.46f * cosf(2.0f * M_PI * i / (size - 1));
    buffer[i] *= window;
  }
}

// Extract MFCC from a single frame
void extract_mfcc_frame(float* frame, float* mfcc) {
  // Pre-emphasis
  for (int i = FRAME_SIZE - 1; i > 0; i--) {
    frame[i] = frame[i] - PRE_EMPHASIS * frame[i - 1];
  }
  
  // Apply Hamming window
  apply_hamming_window(frame, FRAME_SIZE);
  
  // Prepare FFT buffers
  for (int i = 0; i < FRAME_SIZE; i++) {
    fft_real[i] = frame[i];
    fft_imag[i] = 0.0f;
  }
  for (int i = FRAME_SIZE; i < FFT_SIZE; i++) {
    fft_real[i] = 0.0f;
    fft_imag[i] = 0.0f;
  }
  
  // Compute FFT
  fft(fft_real, fft_imag, FFT_SIZE);
  
  // Compute power spectrum
  for (int i = 0; i <= FFT_SIZE / 2; i++) {
    power_spectrum[i] = fft_real[i] * fft_real[i] + fft_imag[i] * fft_imag[i];
  }
  
  // Apply mel filter banks
  for (int i = 0; i < MEL_BINS; i++) {
    mel_energies[i] = 0.0f;
    for (int j = 0; j <= FFT_SIZE / 2; j++) {
      mel_energies[i] += power_spectrum[j] * mel_filters[i][j];
    }
    // Log mel energies (add small epsilon to avoid log(0))
    mel_energies[i] = logf(mel_energies[i] + 1e-10f);
  }
  
  // Apply DCT to get MFCCs
  for (int i = 0; i < NUM_MFCC; i++) {
    mfcc[i] = 0.0f;
    for (int j = 0; j < MEL_BINS; j++) {
      mfcc[i] += dct_matrix[i][j] * mel_energies[j];
    }
  }
}

// ============= I2S FUNCTIONS =============

void init_i2s() {
  i2s_chan_config_t chan_cfg = I2S_CHANNEL_DEFAULT_CONFIG(I2S_PORT, I2S_ROLE_MASTER);
  // Match the legacy driver's dma_buf_count=8/dma_buf_len=256 explicitly --
  // the new API's own defaults (6 descriptors x 240 frames) are close but
  // not identical, and this migration isn't meant to also retune buffering.
  chan_cfg.dma_desc_num  = 8;
  chan_cfg.dma_frame_num = 256;

  esp_err_t err = i2s_new_channel(&chan_cfg, NULL, &mic_rx_handle);  // NULL tx handle: RX only
  if (err != ESP_OK) {
    Serial.print("ERROR: I2S channel creation failed: ");
    Serial.println(err);
    return;
  }
  Serial.println("DEBUG: I2S driver installed");
  Serial.flush();

  i2s_std_config_t std_cfg = {
    .clk_cfg  = I2S_STD_CLK_DEFAULT_CONFIG(SAMPLE_RATE),
    .slot_cfg = I2S_STD_PHILIPS_SLOT_DEFAULT_CONFIG(I2S_DATA_BIT_WIDTH_32BIT, I2S_SLOT_MODE_MONO),
    .gpio_cfg = {
      .mclk = I2S_GPIO_UNUSED,
      .bclk = (gpio_num_t)I2S_SCK,
      .ws   = (gpio_num_t)I2S_WS,
      .dout = I2S_GPIO_UNUSED,
      .din  = (gpio_num_t)I2S_SD,
      .invert_flags = { .mclk_inv = false, .bclk_inv = false, .ws_inv = false },
    },
  };
  // See echosafe_inference.ino's migration (CLAUDE.md, Firmware section):
  // on the S3, I2S_STD_PHILIPS_SLOT_DEFAULT_CONFIG's mono case leaves
  // slot_mask at BOTH regardless of mono/stereo (unlike the original
  // ESP32/ESP32-S2, where it defaults to LEFT) -- the physical slot has to
  // be selected explicitly or the mic's L/R-select pin would be ignored.
  std_cfg.slot_cfg.slot_mask = I2S_STD_SLOT_LEFT;

  err = i2s_channel_init_std_mode(mic_rx_handle, &std_cfg);
  if (err != ESP_OK) {
    Serial.print("ERROR: I2S std mode init failed: ");
    Serial.println(err);
    return;
  }

  err = i2s_channel_enable(mic_rx_handle);
  if (err != ESP_OK) {
    Serial.print("ERROR: I2S channel enable failed: ");
    Serial.println(err);
    return;
  }
  Serial.println("DEBUG: I2S pins configured");
  Serial.flush();
  // No RX equivalent of the legacy i2s_zero_dma_buffer(): the new driver's
  // only "auto clear" options are documented as TX-buffer-only, and an RX
  // buffer's prior contents don't matter since real samples overwrite it on
  // every DMA transfer regardless.
}

// Read audio frame from I2S microphone
void read_audio_frame(float* buffer, int size) {
  size_t bytes_read = 0;
  // timeout_ms is milliseconds here, not RTOS ticks like the legacy
  // i2s_read()'s portMAX_DELAY -- reusing the same constant still means
  // "block for billions of ms," i.e. effectively forever, same as before.
  i2s_channel_read(mic_rx_handle, i2s_buffer, size * sizeof(int32_t), &bytes_read, portMAX_DELAY);

  // Convert 32-bit I2S samples to float and normalize
  for (int i = 0; i < size; i++) {
    buffer[i] = (float)i2s_buffer[i] / 2147483648.0f;  // Normalize to [-1, 1]
  }
}

// ============= FEATURE EXTRACTION =============

void capture_and_extract_features() {
  Serial.println("START_CAPTURE");
  
  unsigned long start_time = millis();
  
  // Capture audio and extract features frame by frame
  float full_audio[FRAME_SIZE + (NUM_FRAMES - 1) * FRAME_STEP];
  
  // Read all audio samples
  for (int i = 0; i < NUM_FRAMES; i++) {
    int offset = i * FRAME_STEP;
    float frame_buffer[FRAME_SIZE];
    read_audio_frame(frame_buffer, FRAME_SIZE);
    
    // Store in full audio buffer
    for (int j = 0; j < FRAME_SIZE; j++) {
      if (offset + j < sizeof(full_audio) / sizeof(float)) {
        full_audio[offset + j] = frame_buffer[j];
      }
    }
    
    // Extract MFCC for this frame
    extract_mfcc_frame(frame_buffer, mfcc_features[i]);
  }
  
  unsigned long capture_time = millis() - start_time;
  
  // Output features in structured format
  Serial.println("FEATURES_START");
  Serial.print("TIMESTAMP:");
  Serial.println(millis());
  Serial.print("SAMPLE_RATE:");
  Serial.println(SAMPLE_RATE);
  Serial.print("NUM_FRAMES:");
  Serial.println(NUM_FRAMES);
  Serial.print("NUM_MFCC:");
  Serial.println(NUM_MFCC);
  Serial.print("CAPTURE_TIME_MS:");
  Serial.println(capture_time);
  
  // Output MFCC features (flattened)
  Serial.println("MFCC_DATA:");
  for (int i = 0; i < NUM_FRAMES; i++) {
    for (int j = 0; j < NUM_MFCC; j++) {
      Serial.print(mfcc_features[i][j], 6);
      if (j < NUM_MFCC - 1) Serial.print(",");
    }
    Serial.println();
  }
  
  Serial.println("FEATURES_END");
  Serial.println("READY_FOR_LABEL");
}

// ============= SETUP =============

void setup() {
  Serial.begin(115200);
  delay(2000);  // Give USB CDC time to enumerate

  Serial.println("\n=== EchoSafe Feature Collector ===");
  Serial.println("DEBUG: Serial working, about to init I2S...");
  Serial.flush();

  // Initialize I2S microphone
  init_i2s();
  Serial.println("DEBUG: I2S init done");
  Serial.flush();
  
  // Pre-compute mel filters and DCT matrix
  init_mel_filters();
  init_dct_matrix();
  Serial.println("✓ Mel filters and DCT matrix initialized");
  
  Serial.println("\nReady for data collection!");
  Serial.println("Commands:");
  Serial.println("  'c' - Capture one sample");
  Serial.println("  'r' - Start continuous recording (auto-capture every 2s)");
  Serial.println("  's' - Stop continuous recording");
  Serial.println();
}

// ============= LOOP =============

void loop() {
  // Check for serial commands
  if (Serial.available() > 0) {
    char cmd = Serial.read();
    
    if (cmd == 'c') {
      Serial.println("\n>>> Capturing single sample...");
      capture_and_extract_features();
    }
    else if (cmd == 'r') {
      continuous_mode = true;
      Serial.println("\n>>> Continuous mode STARTED (capturing every 2 seconds)");
      Serial.println(">>> Press 's' to stop");
    }
    else if (cmd == 's') {
      continuous_mode = false;
      Serial.println("\n>>> Continuous mode STOPPED");
    }
  }
  
  // Continuous recording mode
  if (continuous_mode) {
    capture_and_extract_features();
    delay(2000);  // Wait 2 seconds between captures
  }
  
  delay(10);
}

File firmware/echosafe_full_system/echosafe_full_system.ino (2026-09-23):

/*
 * EchoSafe Full System Firmware
 * ESP32-S3-WROOM-1 N16R8
 *
 * 4x ICS43434 MEMS Microphones (2 I2S buses, stereo pairs)
 * 2x MAX98357A Speakers (parallel, I2S_NUM_1 time-muxed with bottom mics)
 * 4x DRV2605L Haptic Drivers via TCA9548A I2C Mux
 *
 * ── Microphone Wiring ──────────────────────────────────────────────────────────
 *   TOP pair  (I2S_NUM_0):  LRCLK→GPIO4  DOUT→GPIO16  BCLK→GPIO5
 *     Top-Left  (TL): SEL→GND  →  LEFT  channel (WS low)
 *     Top-Right (TR): SEL→3V   →  RIGHT channel (WS high)
 *   BOT pair  (I2S_NUM_1):  LRCLK→GPIO12 DOUT→GPIO18  BCLK→GPIO21
 *     Bot-Left  (BL): SEL→GND  →  LEFT  channel (WS low)
 *     Bot-Right (BR): SEL→3V   →  RIGHT channel (WS high)
 *
 * ── Speaker Wiring ─────────────────────────────────────────────────────────────
 *   Both MAX98357A in parallel: DIN→GPIO47  BCLK→GPIO48  LRC→GPIO45  SD→VIN
 *   Shares I2S_NUM_1 with BOT mics (time-multiplexed: mics during capture,
 *   speaker during alert playback, then mics restored)
 *
 * ── Haptic Wiring ──────────────────────────────────────────────────────────────
 *   TCA9548A I2C Mux: SDA→GPIO9  SCL→GPIO11  A0-A3→GND → address 0x70
 *     Ch 0 → Top-Left  DRV2605L
 *     Ch 1 → Top-Right DRV2605L
 *     Ch 2 → Bot-Left  DRV2605L
 *     Ch 3 → Bot-Right DRV2605L
 *   DRV2605L fixed I2C address: 0x5A on each channel
 *
 * ── Two-Phase Operation ────────────────────────────────────────────────────────
 *   Phase 1 — ML Inference:  I2S_NUM_0 @ 16 kHz ONLY_LEFT (TL mic)
 *   Phase 2 — Direction:     Both ports @ 44.1 kHz RIGHT_LEFT (all 4 mics)
 *   Phase 3 — Alert:         I2S_NUM_1 as speaker TX (WAV from LittleFS)
 *
 * ── WAV Files (upload to LittleFS via Arduino plugin from data/ folder) ─────────
 *   /vehiclehorn.wav   → class 0 (horns)
 *   /bicyclebell.wav   → class 2 (bells)
 *   /gun_shot.wav      → class 3 (gunshots)
 *   /emergencysiren.wav → class 4 (sirens)
 *
 * ── Required Arduino Libraries ────────────────────────────────────────────────
 *   Adafruit DRV2605 Library  (Library Manager: "Adafruit DRV2605")
 *
 * ── Commands ──────────────────────────────────────────────────────────────────
 *   i = single inference   r = continuous   s = stop
 *   h = haptic test        d = direction test
 *   t = tone test (440 Hz) p = speaker test (all WAVs)
 */

#include <driver/i2s.h>
#include <Wire.h>
#include <Adafruit_DRV2605.h>
#include <FS.h>
#include <LittleFS.h>
#include <math.h>
#include "../echosafe_inference/model_weights.h"

// ─── ML INFERENCE PARAMETERS (must match training) ────────────────────────────
#define ML_SAMPLE_RATE     16000
#define ML_NORM_DIV        2147483648.0f  // 2^31 — ICS43434 24-bit left-justified

// ─── DIRECTION DETECTION PARAMETERS ──────────────────────────────────────────
#define DIR_SAMPLE_RATE    44100   // higher rate → finer TDOA resolution
#define DIR_NORM_DIV       8388608.0f  // 2^23 for 24-bit at higher rate

// ─── SHARED MFCC / FFT PARAMETERS ────────────────────────────────────────────
#define FRAME_SIZE         512
#define NUM_MFCC           13
#define NUM_FRAMES         31
#define FFT_SIZE           512
#define MEL_BINS           26
#define PRE_EMPHASIS       0.97f
#define CONFIDENCE_THR     0.65f

// ─── ML MIC CHANNEL ──────────────────────────────────────────────────────────
// ONLY_LEFT  = TL mic (SEL→GND) — switch back to this once TL hardware is fixed
// ONLY_RIGHT = TR mic (SEL→3V)  — in use while TL shows 0.0000 RMS
// IMPORTANT: retrain the model after swapping channels for best accuracy.
// NOTE: model_weights.h was trained on audio from the single-mic reference
// rig (echosafe_feature_collector.ino, GPIO 5/6/7), not from either TL or TR
// on this board's mic array — switching this define does not by itself
// resolve that mismatch. Retraining on audio captured from whichever channel
// is actually used here is the real fix, not just a channel flip.
#define ML_MIC_CHANNEL     I2S_CHANNEL_FMT_ONLY_RIGHT

// ─── ENERGY-TRIGGERED CAPTURE ────────────────────────────────────────────────
// Inference window starts on the first frame whose RMS exceeds this value.
// This aligns the window to the sound onset, which is critical for transient
// sounds like gunshots (otherwise most of the window is silence → "noise").
// Tune: raise if spurious triggers in quiet room, lower for distant sounds.
#define CAPTURE_TRIGGER_RMS  0.003f
// If no sound is heard within this many ms, classify background anyway.
#define CAPTURE_TIMEOUT_MS   2000

// ─── TDOA PARAMETERS ─────────────────────────────────────────────────────────
#define TDOA_FRAMES        1024    // samples per mic for direction capture
#define MAX_LAG            24     // max sample lag to search (≈ 0.54 ms at 44.1 kHz)
#define TDOA_MIN_RMS       0.0005f // below this → signal too quiet to locate

// ─── TOP MIC PAIR (I2S_NUM_0) ─────────────────────────────────────────────────
#define MIC_TOP_WS         4
#define MIC_TOP_BCLK       5
#define MIC_TOP_DOUT       16
#define MIC_TOP_PORT       I2S_NUM_0

// ─── BOTTOM MIC PAIR (I2S_NUM_1, shared with speaker) ────────────────────────
#define MIC_BOT_WS         12
#define MIC_BOT_BCLK       21
#define MIC_BOT_DOUT       18
#define MIC_BOT_PORT       I2S_NUM_1

// ─── SPEAKERS (both MAX98357A in parallel, I2S_NUM_1 TX) ──────────────────────
#define SPK_DIN            47
#define SPK_BCLK           48
#define SPK_LRC            45
#define SPK_PORT           I2S_NUM_1   // same port as BOT mics — time-muxed

// ─── I2C / HAPTICS ────────────────────────────────────────────────────────────
#define I2C_SDA            9
#define I2C_SCL            11
#define TCA_ADDR           0x70   // TCA9548A: A0-A3→GND
#define NUM_HAPTIC         4
#define HAPTIC_TL          0
#define HAPTIC_TR          1
#define HAPTIC_BL          2
#define HAPTIC_BR          3
#define HAPTIC_EFFECT      47   // DRV2605L waveform effect #47 (long buzz)

// ─── WAV ALERT FILES ──────────────────────────────────────────────────────────
const char* WAV_FILES[NUM_CLASSES] = {
  "/vehiclehorn.wav",    // 0: horns
  nullptr,               // 1: noise — no alert
  "/bicyclebell.wav",    // 2: bells
  "/gun_shot.wav",       // 3: gunshots
  "/emergencysiren.wav", // 4: sirens
};

// ─── GLOBAL STATE ─────────────────────────────────────────────────────────────
Adafruit_DRV2605 drv;
bool g_continuous   = false;
bool g_fs_ok        = false;
bool g_haptic_ok[NUM_HAPTIC] = {};

// ─── GLOBAL BUFFERS ───────────────────────────────────────────────────────────
// ML inference (16 kHz, mono TL)
float    g_frame[FRAME_SIZE];
int32_t  g_ml_raw[FRAME_SIZE];
float    g_mfcc[NUM_FRAMES][NUM_MFCC];
float    g_feat[INPUT_DIM];
float    g_l1[128], g_l2[64], g_probs[NUM_CLASSES];

// MFCC intermediates
float    g_fft_re[FFT_SIZE], g_fft_im[FFT_SIZE];
float    g_pspec[FFT_SIZE / 2 + 1];
float    g_mel_e[MEL_BINS];
float    g_mel_fb[MEL_BINS][FFT_SIZE / 2 + 1];
float    g_dct_m[NUM_MFCC][MEL_BINS];
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

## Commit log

2026-06-09 Initial commit: EchoSafe ML pipeline under ML_Model/
    Adds the full ML classification pipeline for EchoSafe — an ESP32-S3
    wearable sound classifier for hearing-impaired users. Includes data
    collection firmware, serial feature logger, model training scripts,
    single-mic and full 4-mic+haptics inference firmware, and repo README.
    [partitions.csv]
2026-06-09 Add hardware design files (KiCad schematics, PCB layouts)
    KiCad project with schematic, PCB layouts (v1, v2, v2_final), and
    custom component libraries for ESP32-S3, ICS-43434 MEMS mics,
    MAX98357A speaker amp, DRV2605 haptic driver, and NPM1300 PMIC.
    Sourced from hardware/ in the sdp26-22 team repo.
    [C0720B001F.step, echosafe.kicad_pcb, echosafe.kicad_sch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]
2026-09-11 Consolidate EchoSafe firmware, ML pipeline, and RevA hardware
    Brings together the current firmware (echosafe_full_system.ino as primary
    target, echosafe_inference.ino as minimal bring-up reference), the ML
    training pipeline and 1059-sample dataset, and the RevA KiCad schematic
    into one project. Superseded firmware drafts, stale training snapshots,
    and the older EchoSafe_Audio pipeline were left out — see
    CONSOLIDATION_NOTES.md for what and why. Originals under ~/Documents/
    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
    [EchoSafe_RevA.kicad_pcb, EchoSafe_RevA.kicad_sch, partitions.csv]
2026-09-11 Apply TL-mic workaround, document Phase 2 hardware/firmware cross-check
    - echosafe_full_system.ino: switch ML_MIC_CHANNEL from ONLY_LEFT to
    ONLY_RIGHT per the firmware's own documented workaround for a dead TL
    mic; note that model_weights.h was trained on the single-mic reference
    rig, not either array channel, so this is a stopgap, not a full fix.
    - CLAUDE.md / CONSOLIDATION_NOTES.md: record that the RevA schematic has
    no signal-level wiring yet (0 net labels, 21 wires, all power-rail only)
    so firmware-vs-schematic pin verification isn't possible until that
    work is done, plus two component-count mismatches (1 DRV2605 vs 4
    needed, no TCA9548A mux, 1 vs 2 MAX98357A amps) found wh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
    [echosafe_full_system.ino]
2026-09-11 Add TCA9548A mux + 3 more DRV2605 chips to RevA schematic, fix sym-lib-table
    - Added TCA9548A (U5, 24-pin TSSOP) to the schematic's embedded symbol
    library, pinout taken directly from TI datasheet SCPS207F (not memory) —
    A0/A1/A2/RESET/SDA/SCL on the left, SD0-7/SC0-7 channel pairs on the
    right, VCC/GND top/bottom. Verified: pin count, uuid uniqueness, and
    reference-designator uniqueness all check out; parenthesis balance of
    the whole .kicad_sch is intact.
    - Duplicated the existing working DRV2605LDGS instance three more times
    (U6, U7, U8) alongside the original U3, giving the 4 independent haptic
    drivers the firmware expects. Placed in open schematic space (x=255,
    y=40/75/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
    [EchoSafe_RevA.kicad_sch]
2026-09-11 Wire I2S, I2C, and haptic-output signal nets in RevA schematic
    Adds every signal net the firmware requires that was previously missing
    entirely (schematic had only power rails wired, 0 signal nets):
    - MIC_TOP_WS/SCK/SD and MIC_BOT_WS/SCK/SD: ESP32 <-> mic pairs (I2S0/I2S1)
    - SPK_DIN/BCLK/LRCLK: ESP32 <-> MAX98357A
    - HAPTIC_SDA/SCL: ESP32 <-> TCA9548A upstream I2C
    - MUX_CH0-3_SDA/SCL: TCA9548A downstream channels <-> each DRV2605
    - MOTOR_*_OUTP/OUTN: each DRV2605 <-> its haptic motor
    - SPK_OUTP/OUTN: MAX98357A <-> both speakers (parallel)
    - Power/enable ties: mic VDD/SEL, MAX98357A enable/VDD, DRV2605 EN/VDD/
    IN-TRIG, TCA9548A address/reset/VCC, all against existing rails
    - no_connect mark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
    [EchoSafe_RevA.kicad_sch]
2026-09-12 Add DRV2605 decoupling caps, fix mic/motor clockwise quadrant assignment
    - Corrected MIC3/MIC4 and M3/M4 quadrant assignment: the initial guess
    (numeric order) was wrong. Actual layout is clockwise: MIC1/M1=TL,
    MIC2/M2=TR, MIC3/M3=BR, MIC4/M4=BL. Fixed by swapping MIC3/MIC4's SEL
    rail (1V8_MIC <-> GND) and renaming the motor-output labels at M3/M4 so
    U7 (mux channel 2, "Bottom-Left") now drives M4 and U8 (channel 3,
    "Bottom-Right") now drives M3 -- the driver-to-channel mapping itself
    didn't change, only which physical motor each driver reaches.
    - Added C6/C7/C8/C9 (0.1uF), one per DRV2605 (U3/U6/U7/U8), each wired
    directly from the driver's REG pin to GND per datasheet recomme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
    [EchoSafe_RevA.kicad_sch]
2026-09-12 Confirm speaker impedance, add USB-C charging connector
    - Speaker impedance confirmed as 8 ohm: 2x8 ohm parallel = 4 ohm, within
    MAX98357A spec. 1-amp decision is now final, not conditional.
    - Added J1, a placeholder USB-C connector (Connector:USB_C_Power_Only,
    embedded symbol -- no real part/footprint chosen yet) exposing VBUS,
    GND, CC1, CC2, SHIELD. Wired directly to the NPM1300 PMIC's own
    VBUS/CC1/CC2 pins (21/23/24) -- no external CC pull-down resistors,
    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
    [EchoSafe_RevA.kicad_sch]
2026-09-12 Replace NPM1300 with TP4056+LD1117V33, add full capacitor BOM, confirm board partition
    Major power architecture rework per user-supplied BOM:
    - Removed NPM1300 PMIC entirely (lib_symbol def, instance, all 21 of its
    original wire segments, and the 7 power-rail labels that only served
    it) -- confirmed before deleting that it was never actually wired even
    in the original pre-consolidation schematic, so nothing real was lost.
    - Removed the placeholder USB-C connector added earlier this session
    (Connector:USB_C_Power_Only, J1) -- superseded by the real part.
    - Added J1 = TP4056_Module (HiLetGo, w/ protection) and LD1 = LD1117V33
    (SparkFun breakout) as new embedded symbols, wired: BT1 <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
    [EchoSafe_RevA.kicad_sch]
2026-09-12 Add per-module wire harness connectors (star topology)
    Adds J2 (Front-Left, 9 pins), J3 (Front-Right, 9 pins), J4 (Rear-Left,
    7 pins), J5 (Rear-Right, 7 pins) -- placeholder generic connectors
    documenting the exact conductor count and signal list each earpiece
    module's cable needs, per the confirmed board partition:
    - Front modules (J2/J3): WS, BCLK, DOUT, 3V3_SYS, GND, motor OUTP/OUTN,
    speaker OUTP/OUTN
    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
    [EchoSafe_RevA.kicad_sch]
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2026-09-23 Assign footprints across all 5 projects, add missing fp-lib-table
    Target confirmed as a compact near-final wearable, not an early bring-up
    prototype -- choices below favor small/soldered over socketed/header.
    Fixed a regression: splitting into 5 projects had wiped the mic
    (LGA_CAV_IVS) and motor (C0720B001F:XDCR_C0720B001F) footprints that
    already existed pre-split -- the instance generator zeroed every new
    component's footprint unconditionally. Restored both from the pre-split
    commit.
    Fixed a second, pre-existing bug: no fp-lib-table ever existed in any
    version of this project (same class of gap as the sym-lib-table issue
    found earlier this session), and three footprint references
    (LGA_CA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
    [EchoSafe_FrontLeft.kicad_sch, EchoSafe_FrontRight.kicad_sch, EchoSafe_RearLeft.kicad_sch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]
2026-09-23 Assign speaker (LS1/LS2) footprint from real part number
    DigiKey 1528-4227-ND = Adafruit #4227 "Mini Oval Speaker," 8 ohm, 1W,
    30x20x5mm -- verified via DigiKey/Adafruit's own product listings, not
    from memory (same standard as the TCA9548A datasheet lookup earlier this
    session).
    Notable finding that changed the footprint choice: this part connects
    via a Molex PicoBlade 1.25mm-pitch 2-pin connector on a ~10mm cable, not
    bare wire leads -- a generic "speaker footprint" assumption would have
    been wrong. Set Footprint to
    Connector_Molex:Molex_PicoBlade_53261-0271_1x02-1MP_P1.25mm_Horizontal,
    confirmed against KiCad's own official footprint library source (unlike
    the JST-SH harness connector na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
    [EchoSafe_FrontLeft.kicad_sch, EchoSafe_FrontRight.kicad_sch]
2026-09-23 Fix JST-SH footprint naming error, verify TP4056 pin spacing
    Resolved both gaps flagged at the end of the footprint pass:
    - JST-SH harness connector names were an unverified guess using a
    "BM0xB-SRSS-TB" prefix. Fetched the actual files from KiCad's own
    kicad-footprints repo and confirmed the real prefix is "SM0xB-SRSS-TB"
    -- JST_SH_SM09B-SRSS-TB_1x09-1MP_P1.00mm_Horizontal (9 signal + 2
    mounting pads) and JST_SH_SM07B-SRSS-TB_1x07-1MP_P1.00mm_Horizontal
    (7 signal + 2 mounting pads) both verified to exist with correct pad
    counts. Fixed all 8 occurrences across all 5 projects (J2/J3/J4/J5 in
    the central pod, one J1 per module).
    - Checked TP4056 module pin spacing against multi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
    [EchoSafe_FrontLeft.kicad_sch, EchoSafe_FrontRight.kicad_sch, EchoSafe_RearLeft.kicad_sch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]
2026-09-23 Fix session-wide Y-axis coordinate bug, power the ESP32 module
    Discovered KiCad is actually installed on this machine and ran real
    kicad-cli sch erc against every schematic for the first time, instead of
    continuing to rely on text-based invariant checks alone. This surfaced a
    fundamental bug affecting every schematic edit made this session:
    Every label/wire/no-connect placed with a nonzero local Y pin offset used
    placement_y + local_y instead of the correct placement_y - local_y --
    KiCad symbol graphics are authored Y-up, the sheet is Y-down, and that
    flip applies even at angle=0/no-mirror. The two formulas only agree when
    local_y=0, which is why isolated spot-checks earlier in the session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
    [EchoSafe_FrontLeft.kicad_sch, EchoSafe_FrontRight.kicad_sch, EchoSafe_RearLeft.kicad_sch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]
2026-09-23 Replace mic footprint with one authored from the real datasheet
    Discovered while starting PCB placement: the original SnapEDA-imported
    LGA_CAV_IVS.kicad_mod (pre-dates this session) doesn't match the real
    ICS-43434 part. Its GND pad (3) is a tiny 0.127x0.127mm corner pad, and
    a non-electrical mechanical hole occupies pad number "6", pushing the
    real 6th electrical pad to "7" -- one off from the schematic symbol's
    pin 6 (SD).
    Fetched and read InvenSense's actual datasheet (DS-000069 Rev 1.0) to
    verify: GND is really a large ring pad (1.025mm inner / 1.625mm outer
    diameter) surrounding the microphone's acoustic port -- nothing like
    what the footprint had.
    Authored a replacement footprint (IC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
    [EchoSafe_FrontLeft.kicad_sch, EchoSafe_FrontRight.kicad_sch, EchoSafe_RearLeft.kicad_sch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]
2026-09-23 Complete PCB layout for all 5 boards, all DRC-clean
    All 4 earpiece module boards and the central pod are now placed, fully
    routed, and verified at 0 DRC violations / 0 unconnected pads via
    kicad-cli. The central pod (the largest/densest board) was routed with
    FreeRouting (Specctra DSN export/import) after hand-scripted routing
    failed to converge; the last few gaps FreeRouting left were fixed by
    hand with precise pad/via clearance geometry. Documented the full
    approach and key lessons in CLAUDE.md for future reference.
    [EchoSafe_FrontLeft.kicad_pcb, EchoSafe_FrontRight.kicad_pcb, EchoSafe_RearLeft.kicad_pcb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]
2026-09-23 Replace TCA9548A RESET direct tie with proper pull-up resistor
    TI's TCA9548A datasheet specifies RESET should connect to VCC through
    a pull-up resistor when unused, not a direct tie. Added R2 (10kΩ,
    matching R1's EN pull-up convention) between RESET and 3V3_SYS.
    Verified with kicad-cli sch erc: same violation count/categories as
    before (211 -> 210), no new unconnected pins.
    [EchoSafe_RevA.kicad_sch]
2026-09-23 Fix TP4056 module footprint shape, sync R2/J1 changes to PCB
    The TP4056 J1 footprint was a generic uniform-pitch 4-pin header, which
    research (product photos + two independently-measured same-family
    boards) shows is the wrong shape entirely -- the real module has all 4
    pins in a single column with uneven spacing. Replaced with a custom
    footprint built from that data (TP4056_Module.pretty), flagged as a
    best estimate pending physical confirmation.
    Also synced the schematic's R2 (TCA9548A RESET pull-up) and the new J1
    footprint through to the actual PCB layout, which hadn't been touched
    since those schematic edits -- rerouted the affected nets around the
    existing copper. Verified via kicad-cl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
    [EchoSafe_RevA.kicad_pcb, EchoSafe_RevA.kicad_sch]
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2026-09-23 Add acoustic port holes to mic modules, fix mic footprint pad positions
    Adding the acoustic port hole (ICS-43434 datasheet: >=0.5mm diameter,
    centered under the GND ring) exposed that the mic footprint's pad
    positions -- authored earlier this session -- didn't match the real
    chip at all: a simple 2x2-corner grid instead of the datasheet's actual
    3-pad/2-pad row layout. Re-derived the correct pad positions from the
    datasheet's mechanical package drawing (DS-000069 Rev 1.2, Figure 15)
    via pixel-level measurement rather than reading dimension lines by eye,
    cross-checked against reconstructed package width and the PIN#1
    reference corner marker.
    Also rebuilt the GND pad as a true annulus (was a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
    [EchoSafe_FrontLeft.kicad_pcb, EchoSafe_FrontRight.kicad_pcb, EchoSafe_RearLeft.kicad_pcb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]
2026-09-23 Visual/silkscreen review: fix footprint FPID prefixes and silkscreen overlaps
    kicad-cli pcb drc was only ever run at default severity, which silently
    excludes the silk_over_copper/silk_overlap/text_height checks. Re-running
    with --severity-all, plus rendering true F.SilkS-only SVGs (previous
    renders mixed in F.Fab assembly-doc text, making boards look far more
    cluttered than they are), surfaced real issues:
    - Every placed footprint on all 5 boards had lost its library prefix
    (bare name, no "Library:" qualifier) despite correct fp-lib-table
    registrations -- pcbnew's Python API doesn't preserve FPID library
    nicknames across a FootprintLoad()/board.Add() round-trip unless
    SetFPID() is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
    [EchoSafe_FrontLeft.kicad_pcb, EchoSafe_FrontRight.kicad_pcb, EchoSafe_RearLeft.kicad_pcb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]
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2026-09-23 Add TP4056 1:1 fit-test template; reject unsourced Gemini dimensions
    User doesn't have the physical HiLetGo TP4056 module yet, so real
    measurement wasn't possible. Generated a printable PDF instead: a real
    instance of the TP4056_Module footprint (not redrawn) placed on an A4
    sheet with a 100mm calibration ruler and instructions, so the printout
    can be checked against a real ruler before trusting any pad alignment,
    and later held up against the physical module once it arrives.
    Also recording a rejected data source: the user first got footprint
    dimensions from Gemini, which returned a 6-pad two-row layout
    contradicting the existing 4-pad single-column design (already
    cross-checked against 3 c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
2026-09-23 Verify all 5 gerber bundles against JLCPCB's real fab pipeline
    Uploaded each outputs/<Project>-gerbers.zip to JLCPCB's instant-quote
    tool via Claude in Chrome (the built-in browser can't do file uploads).
    All 5 boards parsed cleanly: detected dimensions and layer count match
    the actual layout, rendered copper previews match the real .kicad_pcb
    files (correct component placement/silkscreen), and every board priced
    out with no manufacturability warnings at default 2-layer spec.
    Didn't sign in for their full DFM analysis / dedicated Gerber Viewer --
    both require a JLCPCB account, and creating one or signing in on the
    user's behalf is out of bounds.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
2026-09-23 Research part-swap alternatives for TP4056 and mic; no changes made
    User asked whether alternative parts (from a list, originally sourced
    from another AI) might work better and sidestep the physical-
    verification problem. Investigated both with real primary sources
    rather than taking the list at face value.
    Mic (ICS-43434): checked whether the *same* part has a verified
    footprint before considering a swap -- it does. LCSC/EasyEDA has a
    community footprint for this exact part; read its pad coordinates
    directly and compared against this project's datasheet-derived values.
    After accounting for a 90-degree orientation difference, every pad
    position matches exactly (1.8mm and 0.822mm pitches bot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
2026-09-23 Review and fix I2S_NUM_1 mode-switch handling in full-system firmware
    This port's RX (bot mics) / TX (speaker) time-multiplexing was flagged
    in the file's own header comment as a "plausible source of bugs" but
    never actually reviewed. Traced every call site end to end; the core
    switching logic is correct (every normal path restores RX mode via
    restore_bot_mic() before returning), but found and fixed 3 real gaps:
    - init_speaker() unconditionally uninstalls the existing I2S_NUM_1
    driver before attempting the TX install, so a failed install left
    the port with no driver at all -- neither RX nor TX. Both
    play_wav() and play_tone_440() returned early on that failure
    without restoring RX m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
    [echosafe_full_system.ino]
2026-09-23 Set up arduino-cli, compile all 4 firmware sketches for real
    Nothing in firmware/ had ever actually been compiled -- every review so
    far (including the I2S mode-switch fix) was manual code-tracing only,
    since no Arduino toolchain existed on this machine. Installed
    arduino-cli, the ESP32 board package (esp32:esp32 core v3.3.12), and
    compiled against the actual target hardware
    (esp32:esp32:esp32s3, FlashSize=16M, PSRAM=opi -- matching the
    ESP32-S3-WROOM-1 N16R8 this project specs, not just the board family
    default).
    echosafe_full_system.ino, echosafe_inference.ino, and
    echosafe_feature_collector.ino all compile clean, sharing one
    pre-existing, non-urgent warning: driver/i2s.h (the API this fi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
    [uploadLittleFS.ino]
2026-09-23 Fix retrain.py: broken output path, missing noise guard, non-reproducible
    Reviewing the ML pipeline scripts (starting with retrain.py, the
    documented primary retraining command) turned up a live, serious bug:
    OUTPUT_H_FILE pointed at "echosafe_inference/model_weights.h", a path
    that only resolves correctly from ml/ (matching the documented `cd ml
    && python retrain.py` usage) -- but ml/echosafe_inference/ doesn't
    exist anywhere in this repo, only firmware/echosafe_inference/. Running
    the script as documented would train for the full 150 epochs and then
    crash on the final write, never updating the real firmware file.
    Also fixed: no guard against retraining without a noise class, despite
    that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
    [retrain.py]
2026-09-23 Fix train_on_esp32_features.py and serial_logger.py
    train_on_esp32_features.py --export-c (the documented "parametric
    training with more control" path) produced a C header sharing zero
    identifiers with what the firmware actually needs -- generic
    NUM_LAYERS/layer_1_weights naming vs. the NUM_CLASSES/CLASS_NAMES/
    SCALER_MEAN/LAYER0_WEIGHTS etc. the firmware literally #includes and
    references (confirmed by grepping the .ino files, not assumed). Every
    firmware target would have failed to compile with undefined-identifier
    errors if anyone used this documented flag. Rewrote the export to match
    retrain.py's actual format; verified by running --export-c for real and
    compiling echosafe_inference.ino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
    [serial_logger.py, train_on_esp32_features.py]
2026-09-23 Fix TDOA direction-detection: dead computation and top-quadrant bias
    Reviewed detect_direction()/xcorr_lag() (GCC-PHAT-style lag + energy-
    ratio direction logic) from first principles, since it had never been
    checked for correctness, only for the I2S mode-switching around it.
    No hardware exists to test against real audio, so every fix here was
    verified numerically: by mathematical proof, and by porting the exact
    C logic to Python against synthetic signals with known ground truth.
    xcorr_lag(): removed the sqrt(ea*eb) energy normalization applied to
    every lag candidate before comparison. Since it's the same constant
    for every candidate in the argmax search, it can never change which
    lag wins,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
    [echosafe_full_system.ino]
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2026-09-23 Move uploadLittleFS.ino into its own sketch folder
    arduino-cli (and the Arduino IDE) require a sketch's .ino file to live
    in a folder matching its own name -- this one sat directly in
    firmware/, so arduino-cli looked for firmware/firmware.ino and failed.
    Flagged during the earlier compile-everything pass but worked around
    with a temp-folder copy rather than fixed, since it was a structural
    reorganization beyond that pass's "compile and check" scope.
    Moved via git mv to preserve history, and reconfirmed it compiles
    clean directly from the new location -- no workaround needed anymore.
    Updated the two doc references (CLAUDE.md, CONSOLIDATION_NOTES.md).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
    [uploadLittleFS.ino]
2026-09-23 Pin serial_logger.py's label_map to a canonical mapping
    get_label_id() assigned class IDs by order of first appearance during
    a collection session, so the specific mapping every downstream
    consumer relies on (firmware's WAV_FILES[], both training scripts'
    exported CLASS_NAMES) was an accident of session history, not
    something enforced. It's correct for the current dataset only by
    observation -- a future from-scratch collection session (a fresh
    --output path, or a wiped dataset) could silently produce a
    differently-ordered map that trains and exports "successfully" while
    mismatching the firmware's fixed positional class assumptions.
    Confirmed neither training script reconstructs its own labe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
    [serial_logger.py]
2026-09-23 Source real harness cables for the shopping list's flagged gap
    The shopping list's "not in any board BOM" section flagged that the 4
    point-to-point harness cables (2x9-pin front, 2x7-pin rear) aren't
    purchasable parts as written -- just a description of what's needed.
    Went and found real options:
    9-pin (front L/R): solved cleanly. Adafruit #4350, "JST SH 9-Pin Cable
    - 100mm long," $1.95, verified in stock -- confirmed via its own
    product page that it has JST-SH female connectors on both ends, so it
    plugs directly into both the pod's and module's receptacles with zero
    assembly.
    7-pin (rear L/R): no equivalent off-the-shelf part exists -- checked
    Adafruit's own catalog directly rather than a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
2026-09-23 Scope the i2s.h migration and defer it to bring-up
    Before starting this as part of a loose-end cleanup pass, actually
    counted the real scope: 35 I2S call sites in echosafe_full_system.ino
    alone, plus ~10 and ~9 in the other two sketches. Not a mechanical
    find-replace -- i2s_std.h's API is a different object model (channel
    handles, explicit init/enable/disable/delete) vs. the legacy port-
    number model, so every init function would need a from-scratch
    rewrite, including the RX/TX mode-switching logic on I2S_NUM_1 that
    was just carefully audited and fixed real bugs in.
    Presented the scope and risk to the user before touching anything: a
    full rewrite of the least-tested, most hardware-critical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
2026-09-23 Price every line in the shopping list, ~$65 total for one unit
    Every part in the shopping list Artifact was sourced to a real
    distributor/listing but never priced. Got a real current price for
    each -- mostly LCSC (the only major distributor reachable directly
    this session; DigiKey and Jameco both returned Cloudflare bot-check
    pages on every attempt), plus Adafruit/SparkFun for parts already
    sourced there.
    Added price/priceNote fields to every item in the Artifact's JS data
    and a running "estimated total / still to buy" readout in the sticky
    header that recomputes live as checkboxes are ticked, using the same
    per-row state the checklist already tracks.
    Two things worth flagging rather than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
